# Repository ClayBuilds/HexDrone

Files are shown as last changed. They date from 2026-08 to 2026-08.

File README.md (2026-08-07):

# Folding Carbon Fiber Hexacopter

A scratch-built hexacopter with folding carbon fiber arms, positive buoyancy for
over-water recovery, and a backpack-portable transport case. Built around
salvaged 3DR and mRobotics hardware with a modern ESC and radio stack, running
ArduPilot.

**▶ [Build video and flight footage](https://youtu.be/24VfEYux5ME)**

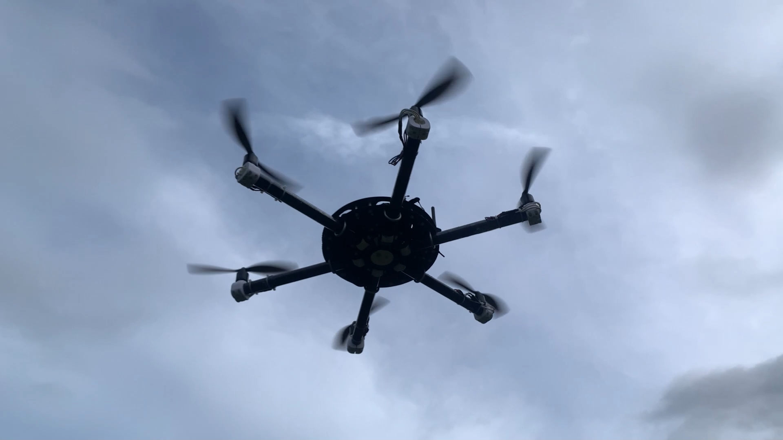
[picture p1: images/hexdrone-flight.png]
Hexacopter in flight


---

## Overview

This project started as a box of used 3DR and Pixhawk parts and grew into a
complete airframe designed around three goals:

1. **Fold for transport.** Each arm pivots on a single bolt and clamps with a
   U-bolt and thumb nuts — no tools required to deploy or stow.
2. **Float after a water landing.** Foam-filled arm tubes and printed
   lightweight-PLA floats keep the aircraft on the surface long enough to
   retrieve it.
3. **Carry it anywhere.** The folded aircraft rides in a sealed drum case with
   backpack straps.

Everything structural is either carbon fiber cut in-house or 3D printed. The
CAD, bill of materials, ArduPilot parameters, and supporting code are all in
this repository.

---

## Specifications

| | |
|---|---|
| Configuration | Hexacopter, X layout |
| Flying weight | **4.83 lb (2.19 kg)** |
| Deployed span | **36.125" prop tip to prop tip** (26.125" motor to motor) |
| Folded envelope | **9.375" diameter × 21.0" tall** |
| Total buoyancy (all floats) | 7.22 lb |
| Propellers | 6 × APC 10×4.7 SFP |
| Battery | 3S LiPo, 5600 mAh (MaxAmps 2P) |
| Thrust-to-weight | ~1.9 : 1 |
| Hover throttle | 51–54 % |
| Frame material | 1/16" carbon fiber plate, 1" OD carbon tube arms |
| Printed parts | PETG (structural), LW-PLA (floats) |
| Autopilot | mRo Control Zero Classic, ArduCopter 4.6.3 |
| Estimated build cost | **$1,382** (see [Cost](#cost) for what this includes) |

### Dimensions

| | Deployed | Folded |
|---|---|---|
| Max diameter | 36.125" (prop tip to prop tip) | **9.375"** |
| Motor centers | 26.125" | — |
| Height | 5.75" (including antennas) | 21.0" with props<br>16.0" without props |

Folding reduces maximum width by nearly 4×. In the stowed position the props
fold parallel to the arms, which accounts for the 5" difference between the
two folded heights.

---

## Measured Performance

All figures below are pulled from actual flight logs, not estimates.

### Speed and range

| Metric | Value |
|---|---|
| Max speed (manual) | **19.4 m/s — 43.3 mph** |
| Max speed (autonomous) | 10.0 m/s — limited by `WPNAV_SPEED` |
| Cruise speed, typical mission | 6.7 m/s average while moving |
| Max demonstrated distance from launch | **421 m (1381 ft)** |
| Longest logged mission | 1273 m ground track in 5.2 min |
| Max altitude flown | 114.6 m (376 ft) |

Top speed is limited by `ANGLE_MAX` (30°) and motor saturation, not by drag —
the aircraft was commanding maximum lean angle and maximum motor output
simultaneously during the fastest runs.

### Power and endurance

| Metric | Value |
|---|---|
| Hover current | ~33 A |
| Peak current observed | 63 A |
| Endurance to low-battery failsafe | ~8–9 min |
| Energy consumed, 5.2 min mission | 32.4 Wh (2863 mAh, 51 % of pack) |
| Efficiency, full mission | 39.3 m/Wh — 129 ft/Wh — 40.9 Wh/mile |
| Efficiency, cruise only (>7 m/s) | 90.3 m/Wh — 296 ft/Wh — 17.8 Wh/mile |

Cruising is roughly 2.3× more efficient per unit distance than a
waypoint-heavy mission, because hovering costs nearly the same power as
forward flight while covering no ground.

### Control performance

Attitude tracking error from a full autonomous mission after tuning:

| Axis | Mean error | 99th percentile | Max |
|---|---|---|---|
| Roll | **0.23°** | 1.43° | 2.99° |
| Pitch | **0.15°** | 1.33° | 3.04° |
| Yaw | 1.21° | 7.34° | 10.28° |

---

## Design Features

### Folding arms

Each arm is a 1" OD × 0.875" ID roll-wrapped carbon tube that pivots on a
single 1/4"-20 bolt through a printed PETG hinge. An aluminum U-bolt and two
thumb nuts clamp the tube against the frame plate to lock it deployed. A
printed arm stabilizer adds rigidity at the joint.

No tools are needed to fold or deploy the aircraft.

### Buoyancy — recovery, not survival

**This is not a waterproof aircraft.** None of the electronics are in sealed
enclosures, and a water landing will almost certainly destroy the flight
controller, ESCs, motors, and radios. The floats exist for exactly one reason:
to keep the airframe on the surface so it can be retrieved rather than lost to
the bottom.

Flying weight is 4.83 lb; total buoyancy with all floats fitted is 7.22 lb,
giving a healthy positive margin.

| Source | Buoyancy (lb) |
|---|---|
| Arms (foam-filled tubes, all 6) | 1.87 |
| Frame assembly | 0.33 |
| Central float | 0.21 |
| "Pizza slice" floats (5) | 1.00 |
| Battery displacement | 0.44 |
| Auxiliary EPS foam float | 3.37 |
| **Total** | **7.22** |

The auxiliary EPS float is fitted only for over-water flights. The printed
floats use lightweight PLA shells with foam interiors.

### Transport case

The folded aircraft rides in a 14-gallon HDPE lab-pack drum with a metal
lever-lock ring, fitted with **backpack straps**. That makes it practical to
hike a fair distance to a launch site, and the sealed drum is equally happy
being shipped or thrown in a truck bed.

Custom foam layers (waterjet-cut, sliced into smaller pieces for
manufacturability) support the body, motor arms, and prop tips. Printed prop
protectors guide the blades into their foam slots during packing.

---

## Hardware

Full details, part numbers, weights, costs, and sourcing links are in
[`Final BOM.ods`](Final%20BOM.ods) (also provided as `.xlsx`).

### Propulsion

| Item | Part | Qty |
|---|---|---|
| Motor | 3DR brushless, salvaged (12N14P) | 6 |
| ESC | Lumenier Razor Pro F4 45 A 2–6S **AM32** | 6 |
| Propeller | APC 10×4.7 SFP slow-flyer pusher | 6 |
| Battery (main) | MaxAmps 3S 5600 mAh 2P | 1 |
| Battery (alt) | Lectron Pro 3S 5200 mAh 50C | 1 |

ESCs run **DShot600**. Each has a 220 µF capacitor across the battery input.

### Avionics

| Item | Part |
|---|---|
| Flight controller | mRo Control Zero Classic (STM32F7) |
| Firmware | ArduCopter 4.6.3 |
| Power module | mRo ACSP4 — 120 A sensing, 5 V / 12 V BEC |
| GPS / compass | u-blox M8N with HMC5883 on printed mast |
| Telemetry | 915 MHz SiK-style, air + ground pair |
| RC receiver | RadioMaster RP4TD ExpressLRS 2.4 GHz diversity |
| RC transmitter | RadioMaster Pocket ELRS M2 |

### FPV

| Item | Part |
|---|---|
| VTX | SpeedyBee TX800, 25–800 mW 5.8 GHz |
| Camera | Caddx Baby Ratel 2, 1200 TVL |
| Goggles | Eachine EV800D diversity with DVR |

### Structure

| Item | Source |
|---|---|
| Frame plates (upper, middle, lower) | 1/16" DragonPlate EconomyPlate, cut in-house |
| Frame gussets (12) | Same stock |
| Arms (6) | DragonPlate 0.875" × 1.0" × 24" roll-wrapped twill tube |
| Arm pivots, motor mounts, stabilizers | 3D printed PETG |
| Floats, camera mount, GPS pedestal, antenna mount | 3D printed LW-PLA / PETG |
| Fasteners | McMaster-Carr aluminum, 4-40 / 6-32 / 1/4"-20 |

Carbon plate was cut with 1/16" DLC-coated carbide end mills.

---

## ArduPilot Configuration

Full parameter file: [`Ardupilot Parameters.params`](Ardupilot%20Parameters.params)

### Frame and motors

```
FRAME_CLASS       = 2        # Hexacopter
FRAME_TYPE        = 1        # X
MOT_PWM_TYPE      = 6        # DShot600
MOT_THST_EXPO     = 0.65
MOT_SPIN_ARM      = 0.10
MOT_SPIN_MIN      = 0.15
MOT_SPIN_MAX      = 0.95
SERVO_BLH_POLES   = 14
```

### Attitude tune

Roll and pitch gains came from a completed AutoTune run on the roll axis and
were copied to pitch (the airframe is symmetric). Yaw was set manually — see
[Known Issues](#known-issues-and-future-work).

```
ATC_RAT_RLL_P     = 0.522     ATC_RAT_PIT_P     = 0.522
ATC_RAT_RLL_I     = 0.522     ATC_RAT_PIT_I     = 0.522
ATC_RAT_RLL_D     = 0.0213    ATC_RAT_PIT_D     = 0.0213
ATC_ANG_RLL_P     = 13.062    ATC_ANG_PIT_P     = 13.062
ATC_ACCEL_R_MAX   = 82000     ATC_ACCEL_P_MAX   = 82000

ATC_RAT_YAW_P     = 0.45
ATC_RAT_YAW_I     = 0.045
ATC_RAT_YAW_D     = 0
ATC_ANG_YAW_P     = 4.5
ATC_ACCEL_Y_MAX   = 27000
```

These gains are roughly 4× the ArduPilot defaults. That is expected for a
heavy, high-inertia airframe swinging 10" props — each unit of motor output
produces a smaller, slower rotational response than on a small quad, so the
controller needs more gain to track the same command.

### Battery monitoring

Both voltage and capacity failsafes are configured. The current sensor was
calibrated empirically against measured pack consumption.

```
BATT_MONITOR      = 4         # analog voltage + current
BATT_VOLT_MULT    = 13.739
BATT_AMP_PERVLT   = 45.1      # calibrated, not the datasheet default
BATT_CAPACITY     = 5600
BATT_LOW_VOLT     = 10.4      # RTL
BATT_CRT_VOLT     = 10.0      # LAND
BATT_LOW_MAH      = 1120      # RTL at 20 % remaining
BATT_CRT_MAH      = 560       # LAND at 10 % remaining
```

### Radio link

ExpressLRS over CRSF on SERIAL5 (UART8):

```
SERIAL5_PROTOCOL  = 23        # RCIN
RC_PROTOCOLS      = 512       # CRSF only
RC_OPTIONS        = 8736      # bit 13 (ELRS 420k), bit 9 (suppress rate msg)
RSSI_TYPE         = 3         # RSSI from CRSF link
```

### Navigation and safety

```
RTL_ALT           = 2000      # 20 m — clears typical central Texas tree line
WPNAV_SPEED       = 1000      # 10 m/s
WPNAV_SPEED_UP    = 250
WPNAV_SPEED_DN    = 150
ANGLE_MAX         = 3000      # 30°
RC9_OPTION        = 4         # RTL on aux switch
ARMING_CHECK      = 13822

FENCE_TYPE        = 7         # polygon + cylinder + max altitude
FENCE_RADIUS      = 300
FENCE_ALT_MAX     = 100
FENCE_ACTION      = 1         # RTL, fallback Land
```

---

## Cost

**$1,382.26** total, but that number is a deliberate over-estimate. It counts:

- Whole sheets, tubes, and filament spools of raw stock rather than the
  fraction actually consumed
- Full fastener packs where only a few pieces are needed
- Ground equipment that never flies — transmitter, FPV goggles, ground
  telemetry radio, transport case and foam
- Tooling (carbide end mills)

Actual spend on the flying aircraft alone is substantially lower. Several
major components (motors, flight controller, GPS, power module, telemetry
radios) were sourced used from eBay.

---

## Repository Contents

```
├── README.md
├── CAD/                              # source CAD, STEP exports, STLs
├── Drone Weight Optimizer/           # battery selection tool + its own README
├── prop dyno data/
│   └── hex drone motor 3s/raw data/  # dynamometer sweeps feeding the optimizer
├── Ardupilot Parameters.params       # full parameter dump
├── Final BOM.ods                     # bill of materials (LibreOffice)
└── Final BOM excel.xlsx              # same, Excel format
```

### Drone Weight Optimizer

[`Drone Weight Optimizer/`](Drone%20Weight%20Optimizer) contains a Python tool
that picks the LiPo pack giving the longest hover time without violating
thrust or current limits. It fits a power-law curve (`I = a · T^b`) to the
propeller dynamometer data in [`prop dyno data/`](prop%20dyno%20data), predicts
hover current for each candidate battery, and ranks them while flagging any
that fail a thrust-to-weight or continuous-discharge check.

Its recommendation for this airframe was the **MaxAmps 5600 mAh 3S2P** — the
pack actually installed. Predicted hover draw was 29.6 A for 11.4 minutes;
measured flight data gives 33.1 A and roughly 10 minutes to full discharge.
The ~12 % optimism is consistent with the tool's stated simplifications, which
ignore voltage sag and assume pure hover.

See the README inside that directory for inputs, configuration, and usage.

---

## Build Notes and Lessons Learned

A few things that cost real time during this build, recorded here in case
they save someone else the trouble.

### ESC current limits

The Lumenier ESCs shipped with a current limit slider that read **"DISABLED"**
at its maximum position, but behaved as though the limit were near zero — the
motors would spin up unloaded and then refuse to accelerate past roughly 30 %
throttle with a prop installed. Moving the slider one notch off "DISABLED" to
a numerically high value (200 A) resolved it completely.

If your motors plateau under load but reach full RPM with props off, check
this before suspecting anything else.

### Compass placement is not enough on its own

An external compass on a mast still picked up severe interference once the
battery leads were repositioned near it. Field magnitude collapsed from
383 mGauss on the ground to 187 mGauss in flight — a ~350 mGauss disturbance
appearing the instant the motors drew flight current, large enough to swamp
Earth's field and corrupt the heading estimate.

The fix was routing the battery leads away from the mast and keeping the
positive and negative conductors paired. Paired leads carry equal and
opposite current, so their fields largely cancel and fall off as 1/r² instead
of 1/r.

**Verification method:** compare field magnitude with motors off versus
running. A healthy install shows almost no change. Anything more than ~10 %
warrants investigation.

### Motor mount fasteners

Two motor mounts worked loose in flight and rotated far enough to tilt the
thrust vectors. Because a tilted motor's tangential thrust component acts
through the full arm length — a much longer lever than the prop reaction
torque used for yaw control — even a few degrees of tilt produced a yaw
disturbance several times larger than the aircraft's entire yaw authority.
The result was an uncontrollable spin with all six motors saturated.

Threadlocker on motor mount fasteners is not optional on this airframe.

### AutoTune on a heavy hex

AutoTune needed several attempts and some manual intervention:

- Yaw initially failed at "Twitch Size Determination" because the stock yaw
  P gain (0.18) was far too low for this airframe. The controller never
  demanded more than 29 % of available yaw output while missing its rate
  target by 35°/s. Manually raising `ATC_RAT_YAW_P` to 0.45 fixed it.
- Ground effect matters. Tuning below ~5 m produced inconsistent results;
  10–15 m worked much better.
- Tune one axis at a time (`AUTOTUNE_AXES`). A full three-axis run does not
  fit in one battery on this aircraft.
- Enter AutoTune from LOITER, then keep hands completely off the sticks. Any
  stick input pauses progress, and AutoTune aborts after 60 seconds of
  failures.

---

## Known Issues and Future Work

- **ESC mounting is poor.** The ESCs are held to the arms with double-sided
  tape and tend to pop loose when the arms are folded and unfolded. They need
  a proper printed cradle or clamp — this is the most obvious thing on the
  list to fix.
- **Yaw tune incomplete.** The yaw axis reached the final Angle P step before
  a battery failsafe ended the session. Current yaw gains are set manually and
  track well enough (1.2° mean error), but a completed AutoTune would refine
  the angle P term.
- **No harmonic notch filtering.** Bidirectional DShot requires a `-bdshot`
  firmware variant, which is not yet flashed. Enabling it would allow
  RPM-based dynamic notch filtering and permit more aggressive gains.
- **Vibration.** Z-axis vibration peaks around 30 m/s² with no IMU clipping.
  Not currently a problem, but prop balancing is the obvious next step.

---

## Acknowledgments

Built on salvaged 3DR and mRobotics hardware. Runs
[ArduPilot](https://ardupilot.org/), whose documentation and log analysis
tooling made the tuning process tractable.

---

## License

MIT — hardware, CAD, and code alike. See [`LICENSE`](LICENSE).

Use it, modify it, build your own. Attribution appreciated but not required.

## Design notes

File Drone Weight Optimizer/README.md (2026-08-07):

# Drone Battery Flight Time Optimizer

Picks the LiPo battery that gives a multirotor the longest hover time without
violating its thrust or current limits.

The script fits a power-law curve to propeller dynamometer data (thrust vs.
current), uses that curve to predict the hover current draw for every candidate
battery, then ranks the batteries by estimated flight time and flags any that
fail a safety check.

## How it works

1. **Load inputs** — battery spec table (`.xlsx`) and a propeller dynamometer
   sweep (`.txt`).
2. **Reject outliers** — dead-band rows (zero thrust or zero current) are
   dropped, a provisional power law is fit, and points more than 2.5σ from the
   fit are removed.
3. **Fit the trendline** — `I = a · T^b`, where `T` is thrust per motor (lbs)
   and `I` is current per motor (amps). R² is reported.
4. **Estimate flight time** — for each battery:

   ```
   total_weight        = empty_weight + battery_weight
   thrust_per_motor    = total_weight / num_motors
   current_per_motor   = a · thrust_per_motor^b
   total_current       = current_per_motor · num_motors
   flight_time (min)   = (capacity_mAh / 1000) / total_current · 60
   ```

5. **Safety checks** — a battery is marked `FAIL` if either check trips:
   - **Thrust:weight** — max measured thrust × motor count must be at least
     2.0× the loaded weight.
   - **Max continuous discharge** — max measured current × motor count must not
     exceed the battery's rated continuous discharge.
6. **Report** — console summary, a text report, and a 3D scatter plot.

The recommended battery is the one with the longest flight time among those
that pass both checks.

## Requirements

Python 3 with:

```bash
pip install pandas numpy scipy matplotlib openpyxl
```

Plotting uses the `TkAgg` backend and calls `plt.show()`, so a display (and
Tk support, e.g. `python3-tk`) is needed for the interactive window. The PNG is
written either way.

## Usage

```bash
python3 drone_optimizer.py
```

Paths are relative to the working directory, so run it from the project root.

## Configuration

Edit the constants at the top of `drone_optimizer.py`:

| Constant | Default | Meaning |
| --- | --- | --- |
| `NUM_MOTORS` | `6` | Number of motors on the airframe |
| `DRONE_EMPTY_WEIGHT_LBS` | `5` | All-up weight excluding the battery |
| `THRUST_WEIGHT_RATIO` | `2.0` | Minimum required thrust:weight ratio |
| `INPUT_DATA_DIR` | `"Input Data"` | Where inputs are read from |
| `OUTPUT_DATA_DIR` | `"Output Data"` | Where results are written |

## Input files

### `Input Data/battery list.xlsx`

Sheet name must be **`MaxAmps 3S LiPo Batteries`**, with these columns:

- `Battery Name`
- `Capacity (mAh)`
- `Weight (lbs)`
- `Price ($)`
- `Max Continuous Discharge (Amps)`

### `Input Data/dynamometer_*.txt`

CSV with `#` comment lines, from a single-motor propeller dynamometer sweep.
The first matching file is used. Required columns: `THRUST_LBS`,
`CURRENT_AMPS` (`PWM_US` is present but unused).

```
# Propeller Dynamometer Test
# Recorded: 2026-03-07T20:30:48.797796
# Points:   101
# Columns:  PWM_US, THRUST_LBS, CURRENT_AMPS
#
PWM_US,THRUST_LBS,CURRENT_AMPS
1000,0.0000,0.0000
...
```

## Output files

- `Output Data/flight_time_results.txt` — parameters used, per-battery table
  with pass/fail reasons, and the recommended battery.
- `Output Data/flight_time_optimizer.png` — 3D scatter of capacity vs. battery
  weight vs. flight time. Blue circles pass, red squares fail thrust:weight,
  red triangles fail the current rating, and the green marker is the pick.

Example console/report output:

```
  Trendline Model          : I = 5.105 * T^1.541  (R² = 0.9963)
  Min Thrust:Weight Ratio  : 2.0:1  (max total thrust = 11.942 lbs)
  Max Burst Current        : 88.13 A total (14.69 A/motor x 6 motors)

OPTIMAL BATTERY:
  Name     : MAXAMPS LiPo 5600mAh 3S2P 11.1v Battery Pack
  Capacity : 5600 mAh
  Weight   : 0.869 lbs
  Flight   : 11.4 minutes
  Hover    : 29.6 A total
```

## Assumptions and limitations

- Hover only — no allowance for climb, wind, or maneuvering.
- Constant current draw for the whole discharge; voltage sag and the usable
  capacity reserve (typically ~80% depth of discharge) are not modeled.
- All motors are assumed identical to the one on the dynamometer, and thrust is
  assumed evenly split between them.
- Treat the results as a comparison between batteries, not an absolute
  endurance prediction.

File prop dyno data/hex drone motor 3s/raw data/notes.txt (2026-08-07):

Full 3s battery 2200mAh 30C lipo SPMX22003S30
Max about 2lb thrust and 15A

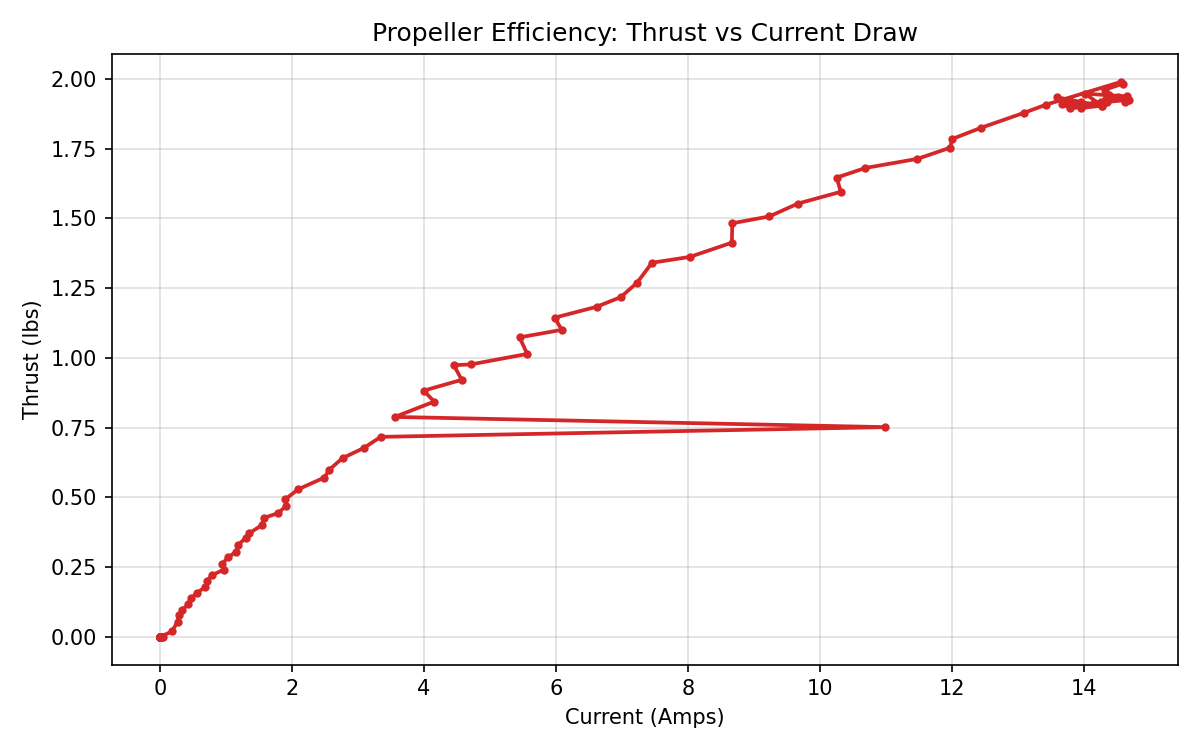
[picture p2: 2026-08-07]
Drone Weight Optimizer/Input Data/plot_thrust_vs_current_20260307_202925.png

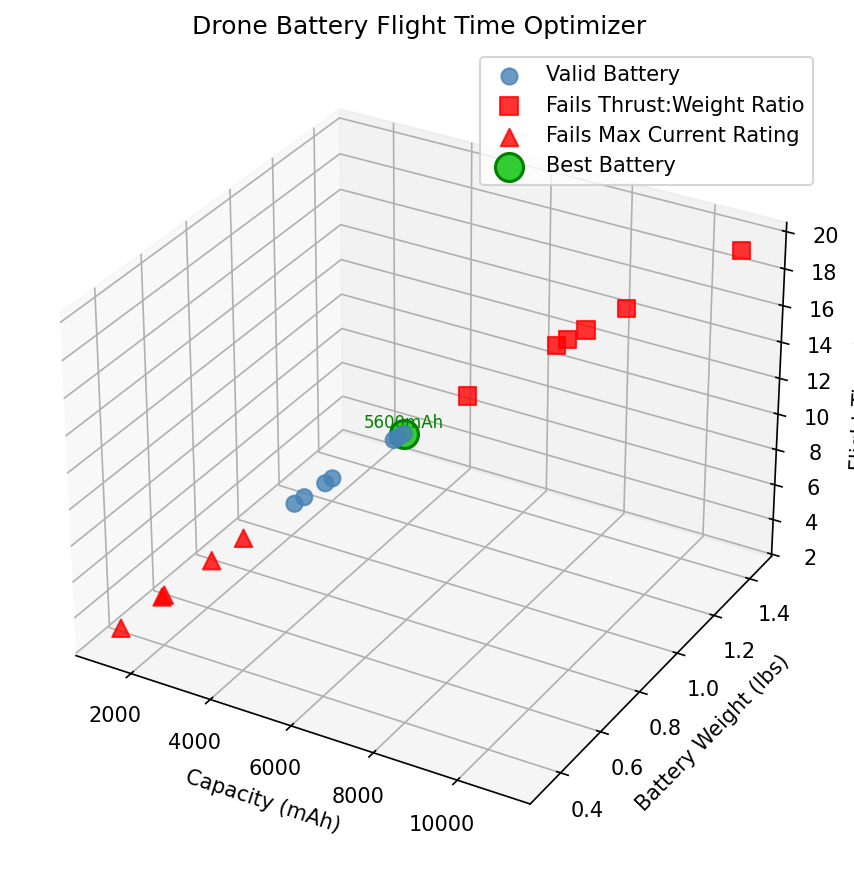
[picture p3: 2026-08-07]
Drone Weight Optimizer/Output Data/flight_time_optimizer.png

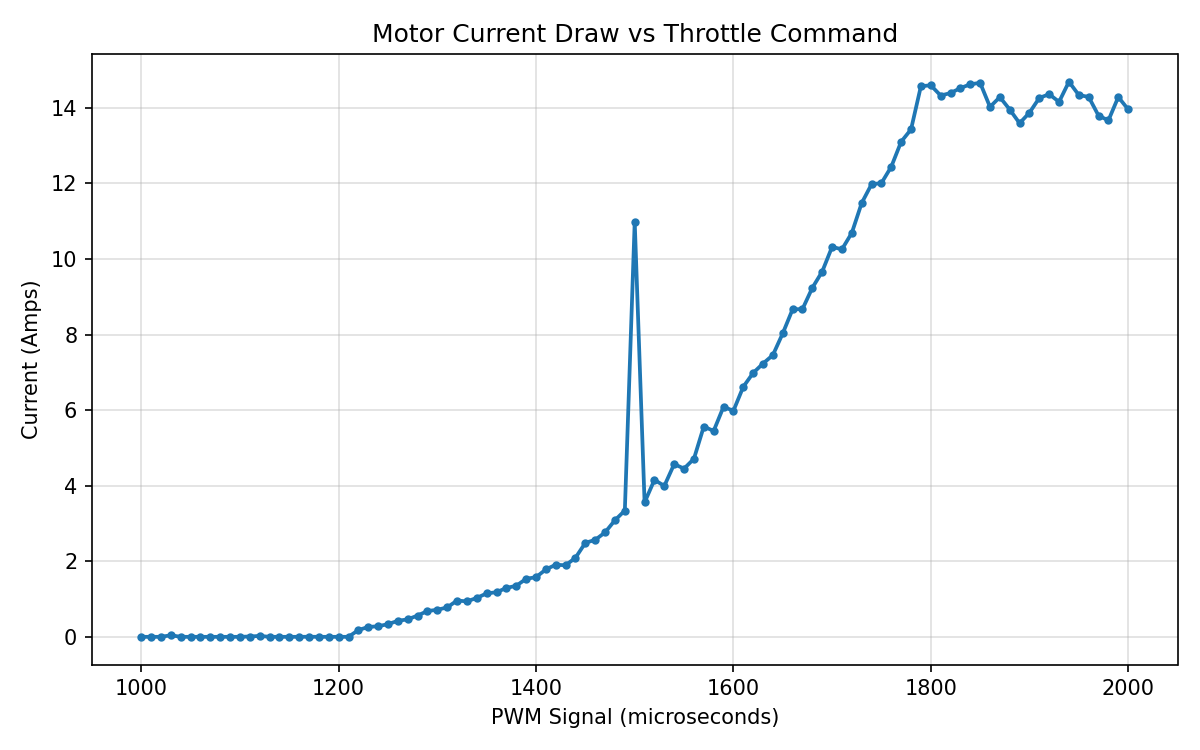
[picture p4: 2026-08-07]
prop dyno data/hex drone motor 3s/raw data/plot_current_vs_pwm_20260307_202925.png

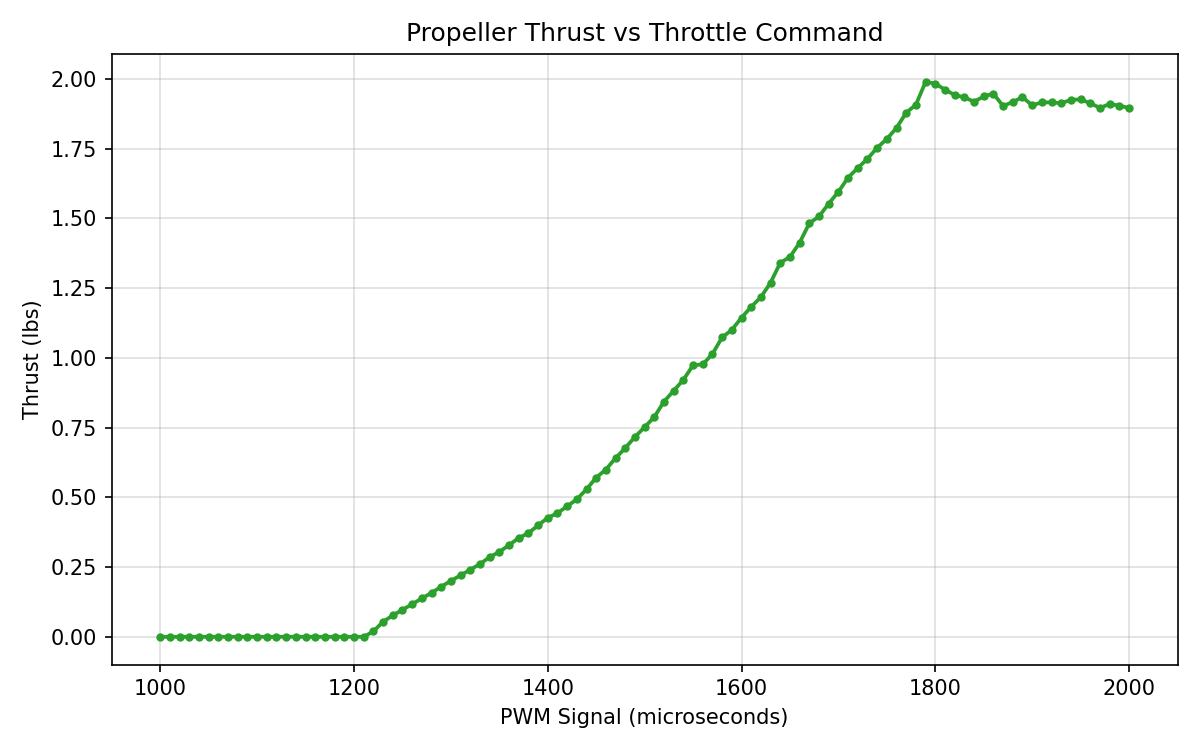
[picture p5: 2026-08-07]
prop dyno data/hex drone motor 3s/raw data/plot_thrust_vs_pwm_20260307_202925.png

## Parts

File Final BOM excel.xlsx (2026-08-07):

HEX DRONE — BILL OF MATERIALS |  |  |  |  |  |  |  |  |  |  |  |  | Corrected copy of BOM2.ods · revised 2026-08-05
Total Cost |  |  |  |  |  |  | Flying Weight (lb) |  |  |  |  |  | Buoyancy — All Floats (lb)
$1382.26 |  |  |  |  |  |  | 4.8315 |  |  |  |  |  | 7.22
Max estimate. Counts whole sheets, tubes and filament spools of raw stock rather than the fraction used, full fastener packs where only a few are needed, and ground gear that never flies — transmitter, goggles, ground radio, case and foam, end mills. Actual spend on the flying aircraft is lower.
IDENTIFICATION |  |  |  |  |  | QUANTITY & STRUCTURE |  |  | MASS & BUOYANCY |  |  |  | COST |  |  |  | SOURCING & NOTES
Item # | My P/N | Manufacturer | Manuf P/N | Name | Description | Qty per Next Assy | Total Qty | Next Assy | Count weight? | Weight Ea. (oz) | Weight Total (lb) | Buoyancy Total (lb) | Count cost? | Cost Ea. ($ per purchase) | Pack Qty (1 if not a pack) | Total Cost ($USD) | Source | Link | Notes
1 | HD0000 | - | N/A | Hex Drone Main Assembly | Full assembly — roll-up row | 1 | 1 | - | - | - | 4.8315 | 7.22 | - | - | - | $1382.26 | - |  | Totals below sum every row in the table. Rows flagged “n” in the count columns are excluded on purpose.
2 | HD0001 | 3DR | Unknown | Motor | 3-phase brushless DC, unknown origin | 1 | 6 | HD0024 | y | 2.46 | 0.9225 | - | y | $5.00 | 1 | $30.00 | eBay (used) |  | Came with 3DR drone parts. Weight includes prop nut.
~~3~~ | ~~HD0002~~ | ~~3DR~~ | ~~Unknown~~ | ~~ESC~~ | ~~3-phase BLDC ESC, 20 A, 1200–1800 µs, with 5 V BEC~~ | ~~6~~ | ~~6~~ | ~~HD0000~~ | ~~n~~ | ~~0.95~~ | ~~—~~ | ~~-~~ | ~~n~~ | ~~$5.00~~ | ~~1~~ | ~~—~~ | ~~eBay (used)~~ |  | ~~Superseded — no longer used, replaced by the Lumenier Razor Pro below. Came with 3DR drone parts. Excluded from both totals.~~
4 | HD0002 | Lumenier | 22300 | ESC | Razor Pro F4 45 A 2–6S AM32 ESC | 6 | 6 | HD0000 | y | 0.20 | 0.075 | - | y | $31.00 | 1 | $186.00 | Lumenier | lumenier.com (https://www.lumenier.com/products/lumenier-razor-pro-f4-45a-2-6s-am32-esc) | Weight includes capacitor (bare spec is 3 g).
5 | HD0003 | APC | LP10047SFP | Propeller | 10x4.7 SFP slow flyer pusher, plastic | 1 | 6 | HD0024 | y | 0.38 | 0.1425 | - | y | $1.00 | 1 | $6.00 | eBay (used) | apcprop.com/10x4-7sf-b4 (https://www.apcprop.com/product/10x4-7sf-b4/?v=7516fd43adaa) | Came with 3DR drone parts. APC spec weight is 0.42 oz; 0.38 oz measured. Link is the LP10047SF-B4 four-pack.
6 | HD0004 | mRobotics | M10048D | Flight Controller | mRo Control Zero Classic autopilot | 1 | 1 | HD0000 | y | 1.37 | 0.0856 | - | y | $80.00 | 1 | $80.00 | eBay (used) | store.3dr.com (https://store.3dr.com/control-zero-classic/) | Came with old mRo stuff. mRobotics board, sold through the 3DR store.
7 | HD0005 | mRobotics | M10026A | Power Module | mRo ACSP4 — 120 A current sensing, 42 V max, 5 V and 12 V 3 A BEC | 1 | 1 | HD0000 | y | 0.66 | 0.0413 | - | y | $19.00 | 1 | $19.00 | eBay (used) | docs.mrobotics.io/acsp4.html (https://docs.mrobotics.io/power-module/acsp4.html) | Came with old mRo stuff.
8 | HD0006 | Unknown | CKHM 2130 | Capacitor | 220 µF 63 V electrolytic capacitor | 1 | 1 | HD0000 | y | 0.08 | 0.005 | - | y | $1.00 | 1 | $1.00 | eBay (used) | - | Came with old mRo stuff.
9 | HD0007 | Unknown | Unknown | GPS Module | Generic Pixhawk GPS with compass, u-blox M8N | 1 | 1 | HD0000 | y | 1.09 | 0.0681 | - | y | $10.00 | 1 | $10.00 | eBay (used) | - | Came with old Pixhawk stuff.
10 | HD0008 | Unknown | Unknown | Telemetry Radio (Air) | 915 MHz air radio, generic Pixhawk SiK style, 6-pin, with antenna and cable | 1 | 1 | HD0000 | y | 0.55 | 0.0344 | - | y | $10.00 | 1 | $10.00 | eBay (used) | - | Came with old Pixhawk stuff. Weight includes cable.
11 | HD0009 | Unknown | Unknown | Telemetry Radio (Ground) | 915 MHz ground radio, generic Pixhawk SiK style, USB | 1 | 1 | HD0000 | n | - | — | - | y | $10.00 | 1 | $10.00 | eBay (used) | - | Came with old Pixhawk stuff. Ground station equipment — does not fly, so weight is excluded but cost is counted.
12 | HD0010 | Radiomaster | HP0157.RX-RP4TD | RC Receiver | ExpressLRS 2.4 GHz diversity receiver | 1 | 1 | HD0000 | y | 0.15 | 0.0094 | - | y | $24.99 | 1 | $24.99 | Radiomaster | radiomasterrc.com (https://radiomasterrc.com/products/rp4td-expresslrs-2-4ghz-diversity-receiver?variant=46486336372928) | Weight includes antennas (bare spec 1.4 g).
13 | HD0011 | Radiomaster | HP0157.0054-M2 | Radio Transmitter | Pocket Radio ELRS M2, FCC | 1 | 1 | HD0000 | n | - | — | - | y | $64.99 | 1 | $64.99 | Radiomaster | radiomasterrc.com (https://radiomasterrc.com/products/pocket-radio-controller-m2) | Ground station equipment — does not fly, weight excluded, cost counted.
14 | HD0012 | SpeedyBee | 16867 | VTX | SpeedyBee TX800 20×20 mm, 25–800 mW 5.8 GHz, MMCX | 1 | 1 | HD0000 | y | 0.20 | 0.0125 | - | y | $51.99 | 1 | $51.99 | RaceDayQuads | racedayquads.com (https://www.racedayquads.com/products/speedybee-tx800-20x20-25-800mw-5-8ghz-vtx-mmcx) | Spec weight 5.6 g (0.20 oz).
15 | HD0013 | Eachine | 17679 | FPV Goggles | EV800D 5.8 GHz 40CH diversity FPV goggles with DVR | 1 | 1 | HD0000 | n | - | — | - | y | $119.99 | 1 | $119.99 | RaceDayQuads | racedayquads.com (https://www.racedayquads.com/products/ev800d-5-8g-40ch-diversity-fpv-goggles-with-dvr) | Ground station equipment — does not fly, weight excluded, cost counted.
16 | HD0014 | Caddx | 15890 | FPV Camera | Baby Ratel 2, 1200 TVL CMOS, 4:3 / 16:9, NTSC/PAL, 1.8 mm, black | 1 | 1 | HD0000 | y | 0.12 | 0.0075 | - | y | $31.49 | 1 | $31.49 | RaceDayQuads | racedayquads.com (https://www.racedayquads.com/products/caddx-baby-ratel-2-1200tvl-cmos-4-3-16-9-ntsc-pal-fpv-camera-1-8mm-black) | Spec weight 3 g (0.11 oz)
17 | HD0015 | McMaster-Carr | 4083A11 | End Mill | Diamond-like carbon-coated carbide end mill, square end, 2 flute, 1/16" dia, 1-1/2" OAL | 2 | 2 | HD0000 | n | - | — | - | y | $30.83 | 1 | $61.66 | McMaster-Carr | mcmaster.com/4083A11 | Tooling for cutting out the carbon fiber sheets — does not fly, weight excluded, cost counted.
18 | HD0016 | McMaster-Carr | 3035T12 | Aluminum U-Bolt | 1/4"-20 thread size, 1" ID | 6 | 6 | HD0000 | y | 0.288 | 0.108 | - | y | $3.41 | 1 | $20.46 | McMaster-Carr | mcmaster.com/3035T12 | Weighed at 0.018 lb (0.288 oz) each. Clamps each arm tube to the frame.
19 | HD0017 | McMaster-Carr | 93886A140 | Thumb Nut | 1/4"-20 thread size, 3/4" head diameter | 12 | 12 | HD0000 | y | 0.16 | 0.120 | - | y | $11.10 | 10 | $22.20 | McMaster-Carr | mcmaster.com/93886A140 | Sold in packs of 10. 12 nuts require 2 packs.
20 | HD0018 | DragonPlate | FEPL02T*90*1212 | Carbon Fiber Sheet | EconomyPlate solid carbon fiber sheet, 1/16" × 12" × 12" | 2 | 2 | HD0000 | n | 7.184 | — | - | y | $61.65 | 1 | $123.30 | DragonPlate | dragonplate.com (https://dragonplate.com/economyplate-solid-carbon-fiber-sheet-1_16-x-12-x-12) | Raw stock — weight excluded because the finished parts (HD0020–HD0022, HD0041) are counted individually; cost is counted here once.
21 | HD0019 | DragonPlate | FDPT.875*1.0*24 | Carbon Fiber Tube | Roll-wrapped twill tube, 0.875" ID × 1.0" OD × 24", gloss finish | 3 | 3 | HD0000 | n | 4.112 | — | - | y | $59.65 | 1 | $178.95 | DragonPlate | dragonplate.com (https://dragonplate.com/carbon-fiber-roll-wrapped-twill-tube-0875-id-x-24-gloss-finish) | Raw stock — weight excluded because the arms (HD0042) are counted individually; cost is counted here once. DragonPlate lists 0.257 lb (4.11 oz) each.
22 | HD0020 | Me | - | Middle Frame Plate | Carbon fiber, cut from HD0018 | 1 | 1 | HD0023 | y | 4.48 | 0.280 | - | n | - | - | — | Made in-house | - | Cost accounted for in the raw material stock (HD0018).
23 | HD0021 | Me | - | Upper Frame Plate | Carbon fiber, cut from HD0018 | 1 | 1 | HD0023 | y | 3.52 | 0.220 | - | n | - | - | — | Made in-house | - | Cost accounted for in the raw material stock (HD0018).
24 | HD0022 | Me | - | Lower Frame Plate | Carbon fiber, cut from HD0018 | 1 | 1 | HD0023 | y | 0.16 | 0.010 | - | n | - | - | — | Made in-house | - | Cost accounted for in the raw material stock (HD0018).
25 | HD0023 | Me | - | Frame Assembly | Whole carbon frame, excluding arms | 1 | 1 | HD0000 | n | - | — | 0.33 | n | - | - | — | Made in-house | - | Subassembly — cost and weight are accounted for in its subcomponents. Buoyancy assumed from calculated volume/displacement.
26 | HD0024 | Me | - | Arm Assembly | Contains motors, tubes, mounts, etc. | 6 | 6 | HD0000 | n | - | — | - | n | - | - | — | Made in-house | - | Subassembly — cost and weight are accounted for in its subcomponents.
27 | HD0025 | Me | - | Arm Pivot | 3D printed | 1 | 6 | HD0024 | y | 0.42 | 0.1575 | - | y | $0.00 | 1 | $0.00 | 3D printed | - | Printed from PETG
28 | HD0026 | Me | - | Motor Mount | 3D printed | 1 | 6 | HD0024 | y | 0.72 | 0.270 | - | y | $0.00 | 1 | $0.00 | 3D printed | - | Printed from PETG
29 | HD0027 | McMaster-Carr | 95856A245 | 1/4-20 Lock Nut | Aluminum nylon-insert lock nut, 1/4"-20, pack of 25 | 1 | 6 | HD0024 | y | 0.064 | 0.024 | - | y | $5.28 | 25 | $5.28 | McMaster-Carr | mcmaster.com/95856A245 | Weight is per nut, not the whole pack. 6 nuts cost one pack.
30 | HD0028 | McMaster-Carr | 8127A81 | VHB Tape | Double-sided foam tape, 1/2" wide | 1 | 1 | HD0000 | n | - | — | - | y | $22.46 | 1 | $22.46 | McMaster-Carr | mcmaster.com/8127A81 | Consumable — the small amount used has negligible mass, so weight is excluded.
31 | HD0029 | McMaster-Carr | 93505A103 | Short Standoff | Male-female threaded hex standoff, aluminum, 3/16" hex, 1/2" long, 4-40 thread | 8 | 8 | HD0000 | y | 0.027 | 0.0135 | - | y | $0.50 | 1 | $4.00 | McMaster-Carr | mcmaster.com/93505A103 | -
32 | HD0030 | McMaster-Carr | 93181A007 | 6-32 Nut | Lightweight 6061 aluminum hex nut, 6-32 thread size | 18 | 18 | HD0000 | y | 0.012 | 0.0135 | - | y | $8.01 | 100 | $8.01 | McMaster-Carr | mcmaster.com/93181A007 | -
33 | HD0031 | McMaster-Carr | 93181A003 | 4-40 Nut | Lightweight 6061 aluminum hex nut, 4-40 thread size | 8 | 8 | HD0000 | y | 0.0065 | 0.0032 | - | y | $7.86 | 100 | $7.86 | McMaster-Carr | mcmaster.com/93181A003 | -
34 | HD0032 | McMaster-Carr | 98511A213 | 4-40 Screw | Aluminum socket head screw, 4-40 × 1/4" long, blue anodized | 8 | 8 | HD0000 | y | 0.007 | 0.0035 | - | y | $12.81 | 10 | $12.81 | McMaster-Carr | mcmaster.com/98511A213 | -
35 | HD0033 | McMaster-Carr | 98511A303 | 6-32 Screw | Aluminum socket head screw, 6-32 × 1/4" long, blue anodized | 18 | 18 | HD0000 | y | 0.012 | 0.0135 | - | y | $10.09 | 10 | $20.18 | McMaster-Carr | mcmaster.com/98511A303 | -
36 | HD0034 | McMaster-Carr | 93306A911 | Arm Pivot Bolt | Hex head screw, 2024 aluminum, 1/4"-20 × 1-3/4" long | 1 | 6 | HD0024 | y | 0.161 | 0.0604 | - | y | $13.99 | 10 | $13.99 | McMaster-Carr | mcmaster.com/93306A911 | -
37 | HD0035 | McMaster-Carr | 93505A446 | Long Standoff | Male-female threaded hex standoff, aluminum, 1" long, 6-32 thread | 18 | 18 | HD0000 | y | 0.16 | 0.180 | - | y | $0.54 | 1 | $9.72 | McMaster-Carr | mcmaster.com/93505A446 | -
38 | HD0036 | Me | - | FPV Camera Mount | 3D printed, fixed | 1 | 1 | HD0000 | y | 0.10 | 0.0063 | - | y | $0.00 | 1 | $0.00 | 3D printed | - | -
~~39~~ | ~~HD0037~~ | ~~Me~~ | ~~-~~ | ~~-~~ | ~~-~~ | ~~-~~ | ~~-~~ | ~~HD0000~~ | ~~n~~ | ~~-~~ | ~~—~~ | ~~-~~ | ~~-~~ | ~~-~~ | ~~-~~ | ~~—~~ | ~~-~~ | ~~-~~ | ~~Part number not used~~
40 | HD0038 | McMaster-Carr | 90362A136 | M2 Screws for Camera | Torx flat head screw, M2, stainless steel, pack of 100 | 2 | 2 | HD0000 | y | - | — | - | n | $5.70 | 100 | — | Already had | - | Weight negligible.
41 | HD0039 | Me | - | RC Antenna Mount | 3D printed; holds both the receiver and its antennas | 1 | 1 | HD0000 | y | 0.10 | 0.0063 | - | y | $0.00 | 1 | $0.00 | 3D printed | - | -
42 | HD0040 | Me | - | GPS Pedestal | 3D printed | 1 | 1 | HD0000 | y | 0.20 | 0.0125 | - | y | $0.00 | 1 | $0.00 | 3D printed | - | -
43 | HD0041 | Me | - | Frame Gusset | Carbon fiber, cut from HD0018 | 12 | 12 | HD0023 | y | 0.16 | 0.120 | - | n | - | - | — | Made in-house | - | Cost accounted for in the raw material stock (HD0018).
44 | HD0042 | Me | - | Arm | Carbon fiber tube, cut to length from stock HD0019 | 1 | 6 | HD0024 | y | 2.05 | 0.7688 | 1.87 | n | - | - | — | Made in-house | - | Cost accounted for in the raw material stock (HD0019). Buoyancy includes the internal foam and uses the full tube OD, and is the total for all 6 arms (≈ 0.31 lb each).
45 | HD0043 | ColorFabb | M-CN2-6S16 | Lightweight Filament | LW-PLA-HT, white, 1.75 mm, 750 g spool | 1 | 1 | HD0000 | n | - | — | - | y | $51.74 | 1 | $51.74 | MatterHackers | matterhackers.com/MCN26S16 (https://www.matterhackers.com/store/l/colorfabb-lw-pla-ht-075kg/sk/MCN26S16) | Raw material — weight excluded; the printed parts made from it carry their own weight. Cost is counted once here.
46 | HD0044 | Me | - | Central Float | Lightweight PLA shell with foam interior; provides emergency buoyancy | 1 | 1 | HD0000 | y | 0.50 | 0.0312 | 0.21 | y | $0.00 | 1 | $0.00 | 3D printed | - | Printed from HD0043 filament.
47 | HD0045 | APC | LPARM12SF | Prop Adapters, Metric | 8 mm to 5 mm adapter rings, 12 sets (3 / 5 / 6 mm) | 1 | 1 | HD0000 | n | - | — | - | y | $2.69 | 1 | $2.69 | APC | apcprop.com (https://www.apcprop.com/product/adapter-rings-metric-sf/?v=7516fd43adaa) | Ring mass is negligible, so weight is excluded; the set price is counted once.
48 | HD0046 | Me | - | Arm Stabilizer | 3D Printed, Provides extra rigidity to the folding arm | 1 | 6 | HD0024 | y | 0.10 | 0.0375 | - | n | - | - | — | 3D printed | - | printed, lightweight PLA
49 | HD0047 | Lectron Pro | 3S5200-50D | Alternate Battery | 3S LiPo 5200 mAh 50C, Deans connector | 1 | 1 | HD0000 | n | 11.45 | — | - | y | $69.99 | 1 | $69.99 | Hobbytown USA | - | Weight excluded — the heavier main battery (HD0056) is counted instead. This is the pack counted for cost.
50 | HD0048 | Me | - | Pizza Slice Float | Lightweight PLA shell with foam interior; provides emergency buoyancy | 5 | 5 | HD0000 | y | 0.20 | 0.0625 | 1.00 | y | $0.00 | 1 | $0.00 | 3D printed | - | Printed from HD0043 filament; the spool cost is counted once on that row. Buoyancy is the total for all 5 (0.2 lb each).
51 | HD0049 | Eagle Manufacturing | 1610MBLK | Cylindrical Container | 14 gal HDPE lab pack drum with metal lever-lock ring — main body of the case assembly | 1 | 1 | HD0050 | n | - | — | - | y | $41.51 | 1 | $41.51 | Eagle Manufacturing | eagle.justrite.com (https://eagle.justrite.com/lab-pack-open-head-poly-drum-14-gallon-metal-lever-lock-black-1610mblk) | Transport container — does not fly, so weight is excluded; cost is counted like the other ground equipment.
52 | HD0050 | Me | - | Case Assembly | Drone fits inside it for transport | 1 | 1 | HD0000 | n | - | — | - | n | - | - | — | Made in-house | - | Subassembly — does not fly, so weight is excluded; cost and weight are accounted for in its components.
53 | HD0051 | SendCutSend | - | 10" Ring Foam | Foam for the case; protects the main drone body | 3 | 3 | HD0050 | n | - | — | - | y | $5.00 | 1 | $15.00 | SendCutSend | - | Cost estimate, custom quote, sliced parts into smaller pieces for cheaper manufacturability. Some manual adjustment required
54 | HD0052 | SendCutSend | - | Lower Foam Layer | Foam for the case; supports the motor arm ends | 2 | 2 | HD0050 | n | - | — | - | y | $5.00 | 1 | $10.00 | SendCutSend | - | Cost estimate, custom quote, sliced parts into smaller pieces for cheaper manufacturability. Some manual adjustment required
55 | HD0053 | SendCutSend | - | Bottom Foam | Bottom foam piece for the case | 1 | 1 | HD0050 | n | - | — | - | y | $5.00 | 1 | $5.00 | SendCutSend | - | Cost estimate, custom quote, sliced parts into smaller pieces for cheaper manufacturability. Some manual adjustment required
56 | HD0054 | SendCutSend | - | Middle Foam | Foam for the case; goes around the motors | 3 | 3 | HD0050 | n | - | — | - | y | $5.00 | 1 | $15.00 | SendCutSend | - | Cost estimate, custom quote, sliced parts into smaller pieces for cheaper manufacturability. Some manual adjustment required
57 | HD0055 | SendCutSend | - | Top Foam | Foam for the case; holds down the top of the drone | 3 | 3 | HD0050 | n | - | — | - | y | $5.00 | 1 | $15.00 | SendCutSend | - | Cost estimate, custom quote, sliced parts into smaller pieces for cheaper manufacturability. Some manual adjustment required
58 | HD0056 | MaxAmps | Lipo-5600-3S2P-Pack-3 | Main Battery | 3S LiPo 5600 mAh (2P) | 1 | 1 | HD0000 | y | 13.69 | 0.8556 | 0.44 | n | $222.00 | 1 | — | MaxAmps | maxamps.com (https://maxamps.com/collections/3s-lipo-battery-11-1v/products/lipo-5600mah-3s2p-11-1v-battery-pack) | Weight counted — this is the heavier of the two packs. Buoyancy = pack volume (1.89 × 4.37 × 1.49 in) × 0.036 lb/in³ fresh water.
59 | HD0057 | Me | - | Auxiliary Foam Float | Attached only when flying over water; ensures positive buoyancy. Cut from EPS foam | 1 | 1 | HD0000 | y | 0.80 | 0.050 | 3.37 | n | - | - | — | Made in-house | - | Fitted only for over-water flights. Cut from EPS foam; material cost negligible.
60 | HD0058 | Me | - | Prop Protector | 3D printed; guides the prop tips into the foam case | 6 | 12 | HD0050 | n | - | — | - | y | $0.00 | 1 | $0.00 | 3D printed | - | Only used for putting the drone in the case — does not fly, weight excluded.

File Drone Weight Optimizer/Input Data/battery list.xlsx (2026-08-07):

Item # | Battery Name | Capacity (mAh) | Weight (lbs) | Price ($) | Max Continuous Discharge (Amps) | SKU | Product Link
1 | MAXAMPS LiPo 4750mAh 3S 11.1v Battery Pack | 4750 | 0.690 | $133.00 | 150 | Lipo-4750-3S-Pack-3 | https://maxamps.com/products/lipo-4750-3s-11-1v-battery-pack
2 | MAXAMPS LiPo 5450mAh 3S 11.1v Battery Pack | 5450 | 0.849 | $169.00 | 163.5 | Lipo-5450-111-Pack-F-3 | https://maxamps.com/products/lipo-5450-3s-11-1v-battery-pack
3 | MAXAMPS LiPo 5600mAh 3S2P 11.1v Battery Pack | 5600 | 0.869 | $210.00 | 140 | Lipo-5600-3S2P-Pack-3 | https://maxamps.com/products/lipo-5600mah-3s2p-11-1v-battery-pack
4 | MAXAMPS LiPo 6500mAh 3S2P 11.1v Battery Pack | 6500 | 1.001 | $210.00 | 149.5 | Lipo-6500-3S2P-Pack-3 | https://maxamps.com/products/lipo-6500-3s2p-11-1v-battery-pack
5 | MAXAMPS LiPo 8000mAh Lite 3S 11.1v Battery Pack | 8000 | 1.140 | $238.00 | 180 | Lipo-8000-Lite-3S-Pack-5 | https://maxamps.com/products/lipo-8000-3s-11-1v-battery-pack
6 | MAXAMPS LiPo 8000mAh 3S2P 11.1v Battery Pack | 8000 | 1.292 | $246.00 | 256 | Lipo-8000-3S2P-Pack-5 | https://maxamps.com/products/lipo-8000-3s2p-11-1v-battery-pack
7 | MAXAMPS LiPo 9000mAh 3S2P 11.1v Battery Pack | 9000 | 1.285 | $246.00 | 207 | Lipo-9000XL-3S2P-Pack-5 | https://maxamps.com/products/lipo-9000xl-3s-11-1v-battery-pack
8 | MAXAMPS LiPo 1300mAh 3S 11.1v Battery Pack | 1300 | 0.333 | $82.00 | 78 | Lipo-1300-3S-Pack-3 | https://maxamps.com/collections/3s-lipo-battery-11-1v/products/lipo-1300-3s-battery
9 | MAXAMPS LiPo 2000mAh 3S 11.1v Battery Pack | 2000 | 0.399 | $97.00 | 54 | Lipo-2000-3S-Pack-10 | https://maxamps.com/collections/3s-lipo-battery-11-1v/products/lipo-2000-3s-11-1v-battery-pack
10 | MAXAMPS LiPo 2800mAh 3S 11.1v Battery Pack | 2800 | 0.485 | $115.00 | 70 | Lipo-2800-3S-Pack-3 | https://maxamps.com/collections/3s-lipo-battery-11-1v/products/https-maxamps-com-collections-lipo-2800mah-packs-products-lipo-2800-3s-7-4v-battery-pack
11 | MAXAMPS LiPo 3250mAh 3S 11.1v Battery Pack | 3250 | 0.551 | $115.00 | 74.75 | Lipo-3250-3S-Pack-3 | https://maxamps.com/collections/3s-lipo-battery-11-1v/products/lipo-3250-3s-11-1v-battery-pack
12 | MAXAMPS Graphene LiPo 3750mAh 3S 11.1v Battery Pack | 3750 | 0.697 | $133.00 | 142.5 | Lipo-3750-3S-Pack-2 | https://maxamps.com/collections/3s-lipo-battery-11-1v/products/graphene-lipo-3750-3s-11-1v-battery-pack
13 | MAXAMPS LiPo 4000mAh 3S 11.1v Battery Pack | 4000 | 0.697 | $133.00 | 128 | Lipo-4000-3S-Pack-3 | https://maxamps.com/collections/3s-lipo-battery-11-1v/products/lipo-4000-3s-11-1v-battery-pack
14 | MAXAMPS LiPo 4500mAh 3S 11.1v Battery Pack | 4500 | 0.703 | $133.00 | 103.5 | Lipo-4500-3S-Pack-3 | https://maxamps.com/collections/3s-lipo-battery-11-1v/products/lipo-4500-3s-11-1v-battery-pack
15 | MAXAMPS Graphene LiPo 5200mAh 3S 11.1v Battery Pack | 5200 | 0.915 | $169.00 | 234 | Graphene-Lipo-5200-3S-Pack-2 | https://maxamps.com/collections/3s-lipo-battery-11-1v/products/graphene-lipo-5200-3s-11-1v-battery
16 | Graphene LiPo 7500mAh 3S2P 11.1v Battery Pack | 7500 | 1.305 | $246.00 | 285 | Graphene-Lipo-7500-3S2P-Pack-3 | https://maxamps.com/collections/3s-lipo-battery-11-1v/products/graphene-lipo-7500-3s2p-11-1v-battery-pack
17 | MAXAMPS LiPo 11000mAh 3S 11.1v Battery Pack | 11000 | 1.444 | $280.00 | 165 | Lipo-11000-3S-Pack-3 | https://maxamps.com/collections/3s-lipo-battery-11-1v/products/lipo-11000-3s-11-1v-battery-pack
18 | SPEKTRUM LiPo 2200mAh 3S 30C | 2200 | 0.375 |  | 66 | SPMX22003S30

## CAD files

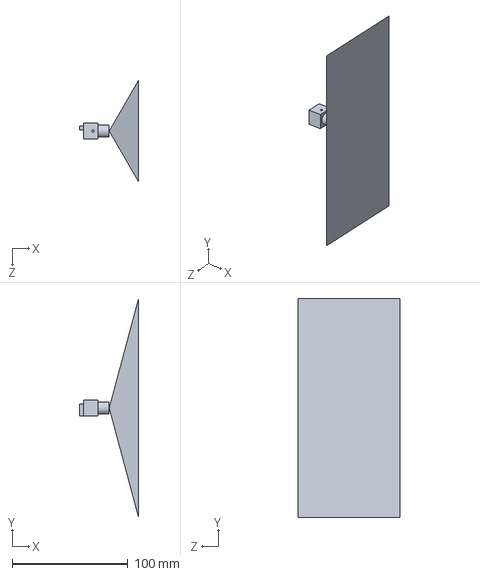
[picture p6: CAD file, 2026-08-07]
CAD/HD0014.SLDPRT
51.2 x 189.6 x 88.0 mm

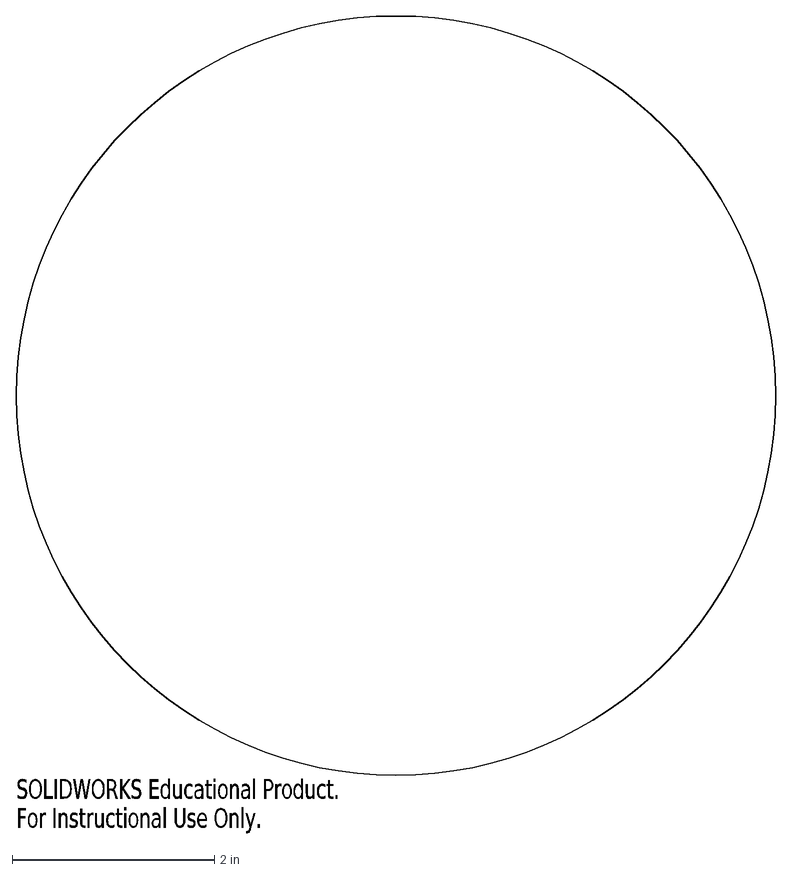
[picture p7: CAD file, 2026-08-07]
CAD/Manufacturing Files/foam cutting/HD0053.DXF
SOLIDWORKS Educational Product.
For Instructional Use Only.

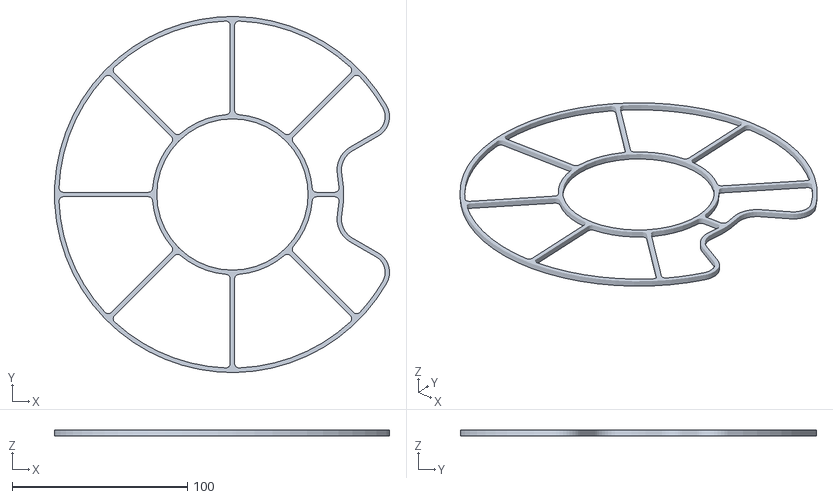
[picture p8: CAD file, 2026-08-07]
CAD/Manufacturing Files/HD0057 TRACING PATTERN.STL
191.3 x 203.2 x 3.17

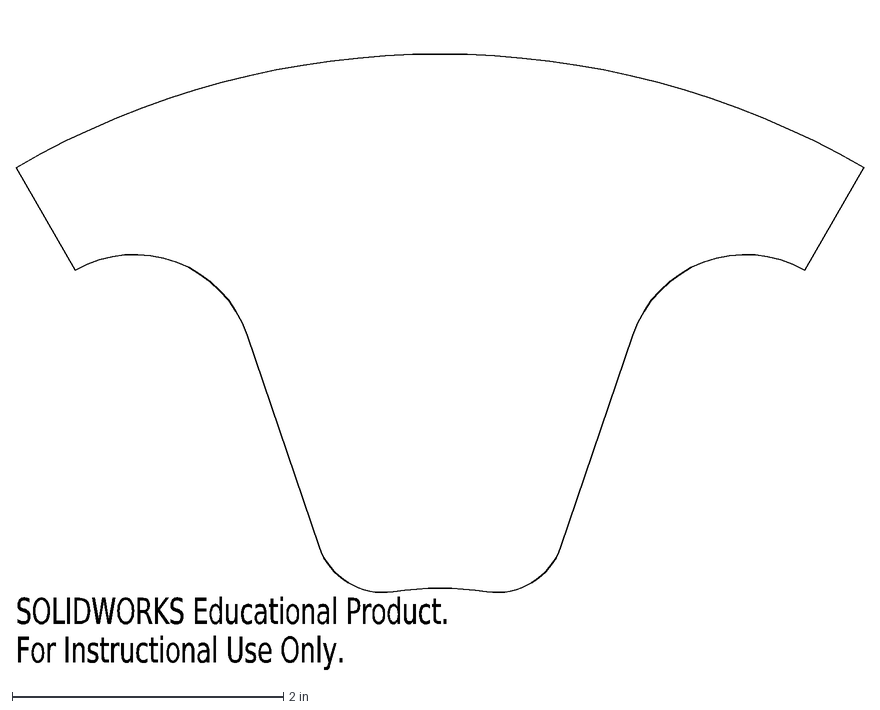
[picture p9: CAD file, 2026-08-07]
CAD/Manufacturing Files/foam cutting/HD0054-001.DXF
SOLIDWORKS Educational Product.
For Instructional Use Only.

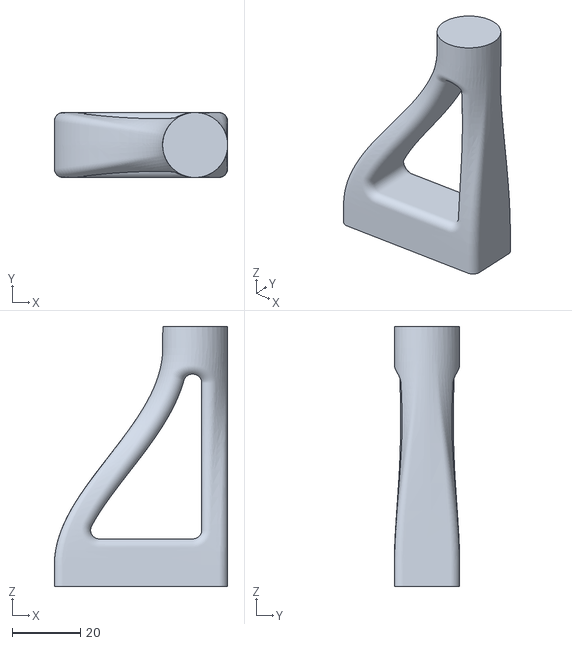
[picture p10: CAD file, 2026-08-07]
CAD/Manufacturing Files/HD0040.STL
50.8 x 19.1 x 76.2

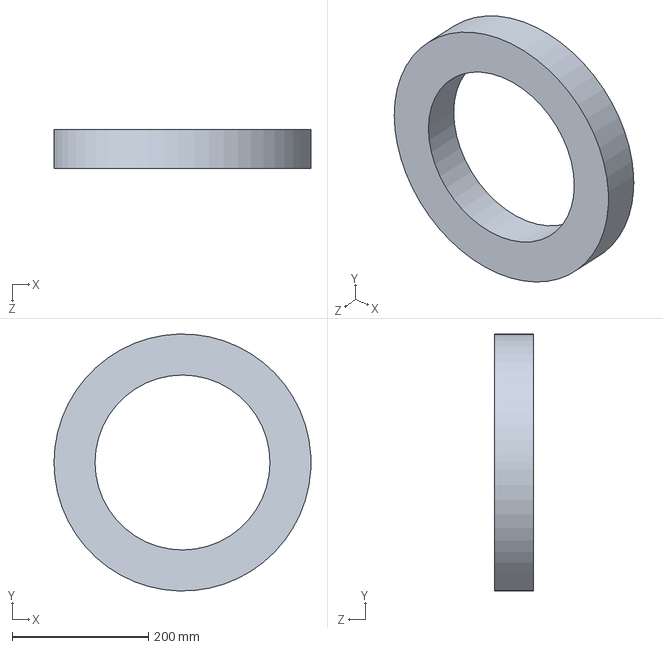
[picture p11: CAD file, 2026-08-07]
CAD/HD0051.SLDPRT
377.8 x 377.7 x 57.1 mm

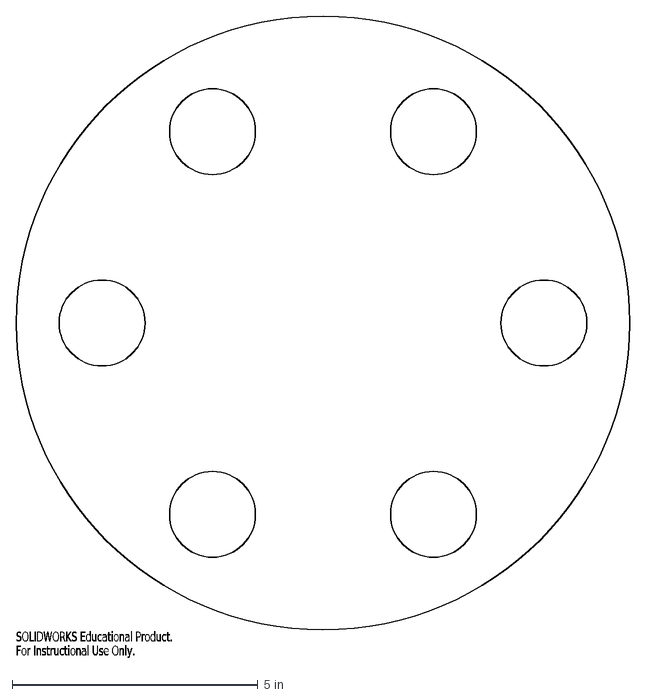
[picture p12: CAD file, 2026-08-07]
CAD/Manufacturing Files/foam cutting/HD0052.DXF
SOLIDWORKS Educational Product.
For Instructional Use Only.

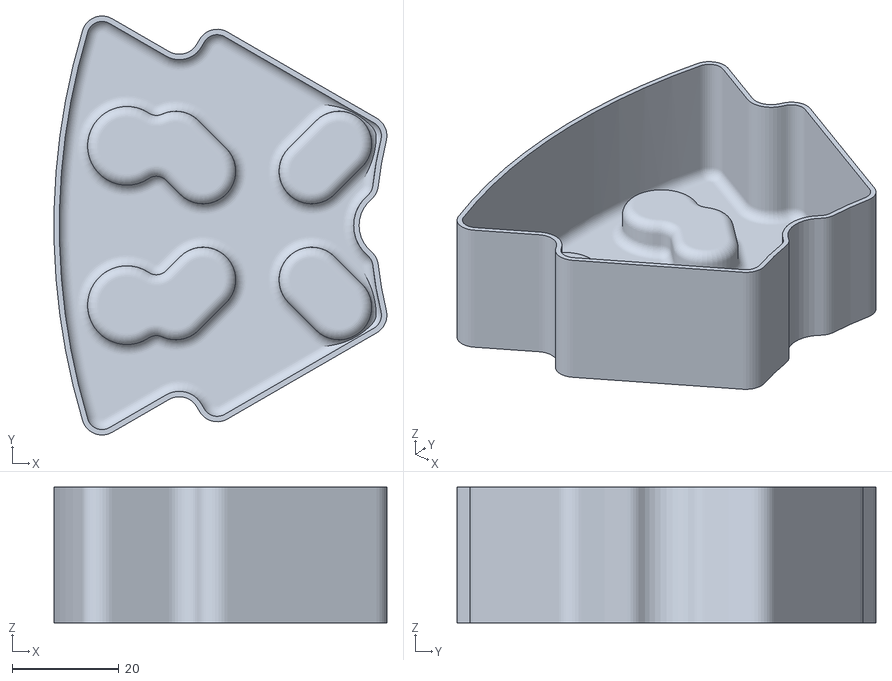
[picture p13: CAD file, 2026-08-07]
CAD/Manufacturing Files/HD0048.STL
62.3 x 78.5 x 25.4

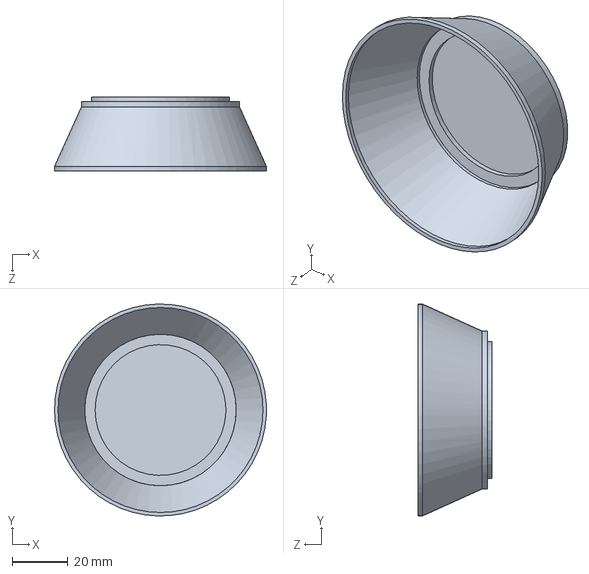
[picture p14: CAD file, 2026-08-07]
CAD/HD0044.SLDPRT
76.2 x 76.2 x 26.5 mm

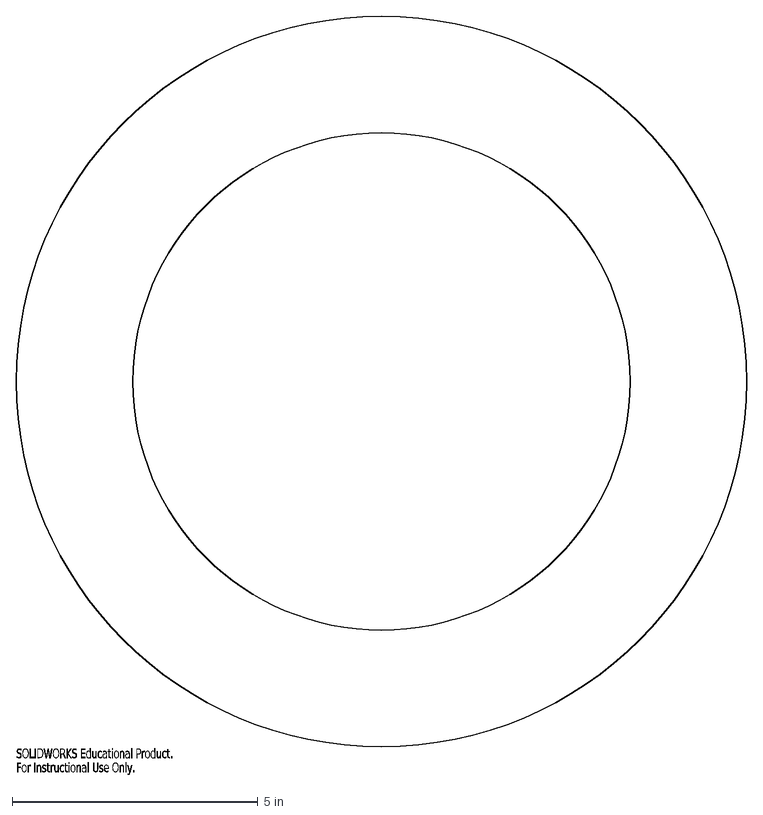
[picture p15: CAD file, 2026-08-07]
CAD/Manufacturing Files/foam cutting/HD0051.DXF
SOLIDWORKS Educational Product.
For Instructional Use Only.

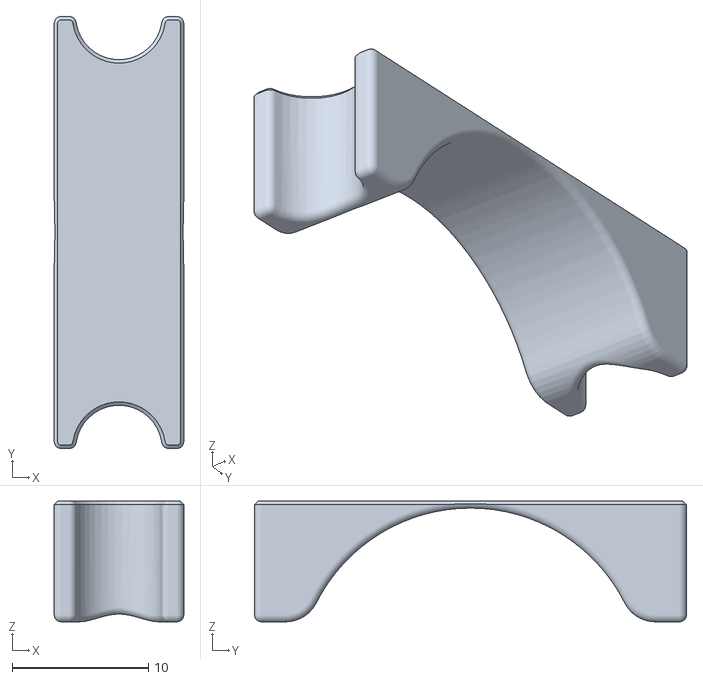
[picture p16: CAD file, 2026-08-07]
CAD/Manufacturing Files/HD0046.STL
9.52 x 31.8 x 8.86

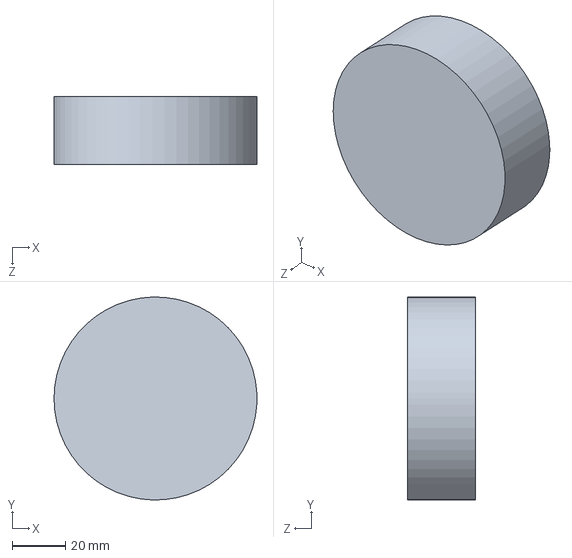
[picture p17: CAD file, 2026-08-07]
CAD/HD0055.SLDPRT
76.2 x 76.2 x 25.4 mm

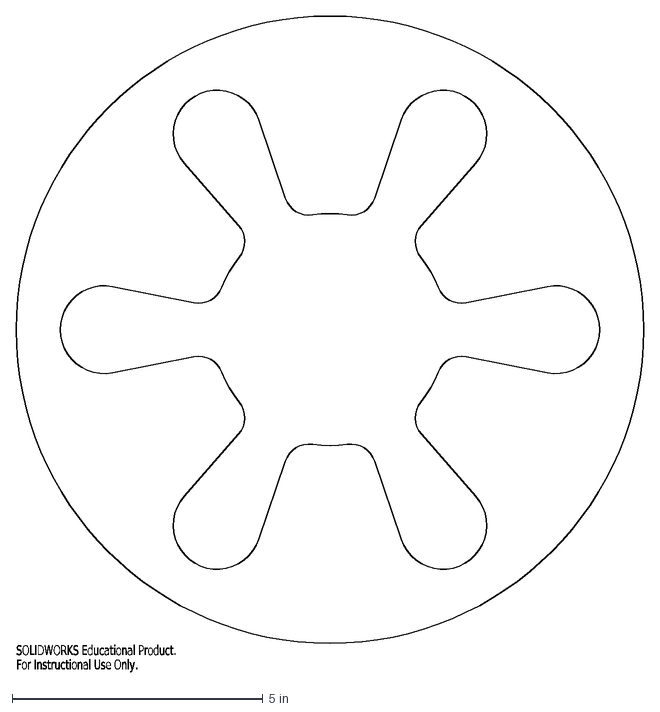
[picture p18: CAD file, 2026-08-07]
CAD/Manufacturing Files/foam cutting/HD0054.DXF
SOLIDWORKS Educational Product.
For Instructional Use Only.

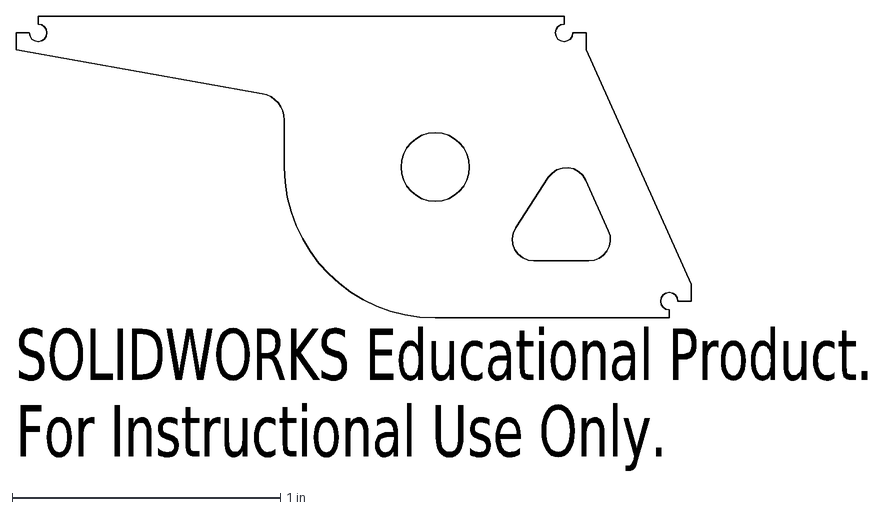
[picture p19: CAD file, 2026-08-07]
CAD/Manufacturing Files/HD0041.DXF
SOLIDWORKS Educational Product.
For Instructional Use Only.

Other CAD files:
CAD/HD0024.SLDASM
CAD/HD0050.SLDASM
CAD/HD0000.SLDASM
CAD/Manufacturing Files/foam cutting/HD0051-001.DXF
CAD/3035T12_Aluminum U-Bolt.SLDPRT
CAD/90362A136_18-8 Stainless Steel Pan Head Torx Screws.SLDPRT
CAD/93181A003_Lightweight 6061 Aluminum Hex Nuts.SLDPRT
CAD/93181A007_Lightweight 6061 Aluminum Hex Nuts.SLDPRT
CAD/93306A546_Hex Head Screw.SLDPRT
CAD/93306A911_Hex Head Screw.SLDPRT
CAD/93505A103_Male-Female Threaded Hex Standoff.SLDPRT
CAD/93505A446_Male-Female Threaded Hex Standoff.SLDPRT
CAD/93886A140_Reinforced Plastic Knurled-Head Thumb Nut.SLDPRT
CAD/95856A245_Aluminum Nylon-Insert Locknut.SLDPRT
CAD/98511A213_Aluminum Socket Head Screw.SLDPRT
CAD/98511A303_Aluminum Socket Head Screw.SLDPRT
CAD/HD0001.SLDPRT
CAD/HD0002.SLDPRT
CAD/HD0003.SLDPRT
CAD/HD0004.SLDPRT
CAD/HD0005.SLDPRT
CAD/HD0007.SLDPRT
CAD/HD0008.SLDPRT
CAD/HD0011.SLDPRT
CAD/HD0012.SLDPRT
CAD/HD0019.SLDPRT
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

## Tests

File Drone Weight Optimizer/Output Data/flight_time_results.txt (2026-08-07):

============================================================
        DRONE BATTERY FLIGHT TIME OPTIMIZER
============================================================

CALCULATION PARAMETERS:
  Number of Motors         : 6
  Empty Drone Weight       : 5.00 lbs
  Dynamometer File         : dynamometer_20260307_202925.txt
  Trendline Model          : I = 5.105 * T^1.541  (R² = 0.9963)
  Outliers Removed         : 1 point
  Min Thrust:Weight Ratio  : 2.0:1  (max single-motor thrust = 1.990 lbs, max total thrust = 11.942 lbs)
  Max Burst Current        : 88.13 A total (14.69 A/motor x 6 motors)

RESULTS:
   #  Battery Name                                         Cap      Wt   Hover A     Time  Status
  ------------------------------------------------------------------------------------------------------
   1  MAXAMPS LiPo 4750mAh 3S 11.1v Battery Pack          4750   0.690    28.22A    10.1m  OK
   2  MAXAMPS LiPo 5450mAh 3S 11.1v Battery Pack          5450   0.849    29.45A    11.1m  OK
 * 3  MAXAMPS LiPo 5600mAh 3S2P 11.1v Battery Pack        5600   0.869    29.60A    11.4m  OK
   4  MAXAMPS LiPo 6500mAh 3S2P 11.1v Battery Pack        6500   1.001    30.64A    12.7m  FAIL: Thrust:weight ratio 1.99:1 < 2.0:1 required
   5  MAXAMPS LiPo 8000mAh Lite 3S 11.1v Battery Pack     8000   1.140    31.74A    15.1m  FAIL: Thrust:weight ratio 1.94:1 < 2.0:1 required
   6  MAXAMPS LiPo 8000mAh 3S2P 11.1v Battery Pack        8000   1.292    32.96A    14.6m  FAIL: Thrust:weight ratio 1.90:1 < 2.0:1 required
   7  MAXAMPS LiPo 9000mAh 3S2P 11.1v Battery Pack        9000   1.285    32.90A    16.4m  FAIL: Thrust:weight ratio 1.90:1 < 2.0:1 required
   8  MAXAMPS LiPo 1300mAh 3S 11.1v Battery Pack          1300   0.333    25.54A     3.1m  FAIL: Max burst current 88.1A exceeds battery rating 78.0A
   9  MAXAMPS LiPo 2000mAh 3S 11.1v Battery Pack          2000   0.399    26.03A     4.6m  FAIL: Max burst current 88.1A exceeds battery rating 54.0A
  10  MAXAMPS LiPo 2800mAh 3S 11.1v Battery Pack          2800   0.485    26.67A     6.3m  FAIL: Max burst current 88.1A exceeds battery rating 70.0A
  11  MAXAMPS LiPo 3250mAh 3S 11.1v Battery Pack          3250   0.551    27.17A     7.2m  FAIL: Max burst current 88.1A exceeds battery rating 74.8A
  12  MAXAMPS Graphene LiPo 3750mAh 3S 11.1v Battery Pack    3750   0.697    28.28A     8.0m  OK
  13  MAXAMPS LiPo 4000mAh 3S 11.1v Battery Pack          4000   0.697    28.28A     8.5m  OK
  14  MAXAMPS LiPo 4500mAh 3S 11.1v Battery Pack          4500   0.703    28.32A     9.5m  OK
  15  MAXAMPS Graphene LiPo 5200mAh 3S 11.1v Battery Pack    5200   0.915    29.96A    10.4m  OK
  16  Graphene LiPo 7500mAh 3S2P 11.1v Battery Pack       7500   1.305    33.06A    13.6m  FAIL: Thrust:weight ratio 1.89:1 < 2.0:1 required
  17  MAXAMPS LiPo 11000mAh 3S 11.1v Battery Pack        11000   1.444    34.19A    19.3m  FAIL: Thrust:weight ratio 1.85:1 < 2.0:1 required
  18  SPEKTRUM LiPo 2200mAh 3S 30C                        2200   0.375    25.85A     5.1m  FAIL: Max burst current 88.1A exceeds battery rating 66.0A

OPTIMAL BATTERY:
  Name     : MAXAMPS LiPo 5600mAh 3S2P 11.1v Battery Pack
  Capacity : 5600 mAh
  Weight   : 0.869 lbs
  Price    : $210
  Flight   : 11.4 minutes
  Hover    : 29.6 A total
============================================================

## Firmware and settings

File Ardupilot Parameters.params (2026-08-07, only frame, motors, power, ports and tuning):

1	1	ATC_ANGLE_BOOST	1	2
1	1	ATC_ANG_LIM_TC	1.000000000000000000	9
1	1	ATC_ANG_PIT_P	13.062000274658203125	9
1	1	ATC_ANG_RLL_P	13.062000274658203125	9
1	1	ATC_ANG_YAW_P	4.500000000000000000	9
1	1	ATC_RATE_FF_ENAB	1	2
1	1	ATC_RATE_P_MAX	0.000000000000000000	9
1	1	ATC_RATE_R_MAX	0.000000000000000000	9
1	1	ATC_RATE_Y_MAX	0.000000000000000000	9
1	1	ATC_RAT_PIT_D	0.021299999207258224	9
1	1	ATC_RAT_PIT_D_FF	0.000000000000000000	9
1	1	ATC_RAT_PIT_FF	0.000000000000000000	9
1	1	ATC_RAT_PIT_FLTD	20.000000000000000000	9
1	1	ATC_RAT_PIT_FLTE	0.000000000000000000	9
1	1	ATC_RAT_PIT_FLTT	20.000000000000000000	9
1	1	ATC_RAT_PIT_I	0.522000014781951904	9
1	1	ATC_RAT_PIT_IMAX	0.500000000000000000	9
1	1	ATC_RAT_PIT_NEF	0	2
1	1	ATC_RAT_PIT_NTF	0	2
1	1	ATC_RAT_PIT_P	0.522000014781951904	9
1	1	ATC_RAT_PIT_PDMX	0.000000000000000000	9
1	1	ATC_RAT_PIT_SMAX	0.000000000000000000	9
1	1	ATC_RAT_RLL_D	0.021299999207258224	9
1	1	ATC_RAT_RLL_D_FF	0.000000000000000000	9
1	1	ATC_RAT_RLL_FF	0.000000000000000000	9
1	1	ATC_RAT_RLL_FLTD	20.000000000000000000	9
1	1	ATC_RAT_RLL_FLTE	0.000000000000000000	9
1	1	ATC_RAT_RLL_FLTT	20.000000000000000000	9
1	1	ATC_RAT_RLL_I	0.522000014781951904	9
1	1	ATC_RAT_RLL_IMAX	0.500000000000000000	9
1	1	ATC_RAT_RLL_NEF	0	2
1	1	ATC_RAT_RLL_NTF	0	2
1	1	ATC_RAT_RLL_P	0.522000014781951904	9
1	1	ATC_RAT_RLL_PDMX	0.000000000000000000	9
1	1	ATC_RAT_RLL_SMAX	0.000000000000000000	9
1	1	ATC_RAT_YAW_D	0.000000000000000000	9
1	1	ATC_RAT_YAW_D_FF	0.000000000000000000	9
1	1	ATC_RAT_YAW_FF	0.000000000000000000	9
1	1	ATC_RAT_YAW_FLTD	20.000000000000000000	9
1	1	ATC_RAT_YAW_FLTE	2.500000000000000000	9
1	1	ATC_RAT_YAW_FLTT	20.000000000000000000	9
1	1	ATC_RAT_YAW_I	0.045000001788139343	9
1	1	ATC_RAT_YAW_IMAX	0.500000000000000000	9
1	1	ATC_RAT_YAW_NEF	0	2
1	1	ATC_RAT_YAW_NTF	0	2
1	1	ATC_RAT_YAW_P	0.449999988079071045	9
1	1	ATC_RAT_YAW_PDMX	0.000000000000000000	9
1	1	ATC_RAT_YAW_SMAX	0.000000000000000000	9
1	1	BATT2_MONITOR	0	2
1	1	BATT3_MONITOR	0	2
1	1	BATT4_MONITOR	0	2
1	1	BATT5_MONITOR	0	2
1	1	BATT6_MONITOR	0	2
1	1	BATT7_MONITOR	0	2
1	1	BATT8_MONITOR	0	2
1	1	BATT9_MONITOR	0	2
1	1	BATT_AMP_OFFSET	0.000000000000000000	9
1	1	BATT_AMP_PERVLT	45.099998474121093750	9
1	1	BATT_ARM_MAH	0	6
1	1	BATT_ARM_VOLT	0.000000000000000000	9
1	1	BATT_CAPACITY	5600	6
1	1	BATT_CRT_MAH	560.000000000000000000	9
1	1	BATT_CRT_VOLT	10.000000000000000000	9
1	1	BATT_CURR_PIN	15	2
1	1	BATT_FS_CRT_ACT	1	2
1	1	BATT_FS_LOW_ACT	2	2
1	1	BATT_FS_VOLTSRC	0	2
1	1	BATT_LOW_MAH	1120.000000000000000000	9
1	1	BATT_LOW_TIMER	10	2
1	1	BATT_LOW_VOLT	10.399999618530273438	9
1	1	BATT_MONITOR	4	2
1	1	BATT_OPTIONS	0	6
1	1	BATT_SERIAL_NUM	-1	6
1	1	BATT_VLT_OFFSET	0.000000000000000000	9
1	1	BATT_VOLT_MULT	13.739241600036621094	9
1	1	BATT_VOLT_PIN	4	2
1	1	FLTMODE1	2	2
1	1	FLTMODE2	2	2
1	1	FLTMODE3	5	2
1	1	FLTMODE4	5	2
1	1	FLTMODE5	3	2
1	1	FLTMODE6	3	2
1	1	FLTMODE_CH	6	2
1	1	FLTMODE_GCSBLOCK	0	6
1	1	FRAME_CLASS	2	2
1	1	FRAME_TYPE	1	2
1	1	INS_GYRO_FILTER	20	4
1	1	INS_HNTCH_ENABLE	0	2
1	1	MOT_BAT_CURR_MAX	0.000000000000000000	9
1	1	MOT_BAT_CURR_TC	5.000000000000000000	9
1	1	MOT_BAT_IDX	0	2
1	1	MOT_BAT_VOLT_MAX	0.000000000000000000	9
1	1	MOT_BAT_VOLT_MIN	0.000000000000000000	9
1	1	MOT_BOOST_SCALE	0.000000000000000000	9
1	1	MOT_HOVER_LEARN	2	2
1	1	MOT_OPTIONS	0	4
1	1	MOT_PWM_MAX	2000	4
1	1	MOT_PWM_MIN	1000	4
1	1	MOT_PWM_TYPE	6	2
1	1	MOT_SAFE_DISARM	0	2
1	1	MOT_SAFE_TIME	1.000000000000000000	9
1	1	MOT_SLEW_DN_TIME	0.000000000000000000	9
1	1	MOT_SLEW_UP_TIME	0.000000000000000000	9
1	1	MOT_SPIN_ARM	0.100000001490116119	9
1	1	MOT_SPIN_MAX	0.949999988079071045	9
1	1	MOT_SPIN_MIN	0.150000005960464478	9
1	1	MOT_SPOOL_TIME	0.500000000000000000	9
1	1	MOT_SPOOL_TIM_DN	0.000000000000000000	9
1	1	MOT_THST_EXPO	0.649999976158142090	9
1	1	MOT_THST_HOVER	0.623103797435760498	9
1	1	MOT_YAW_HEADROOM	200	4
1	1	SERIAL0_BAUD	115	6
1	1	SERIAL0_PROTOCOL	2	2
1	1	SERIAL1_BAUD	57	6
1	1	SERIAL1_OPTIONS	0	4
1	1	SERIAL1_PROTOCOL	2	2
1	1	SERIAL2_BAUD	9	6
1	1	SERIAL2_OPTIONS	4	4
1	1	SERIAL2_PROTOCOL	44	2
1	1	SERIAL3_BAUD	230	6
1	1	SERIAL3_OPTIONS	0	4
1	1	SERIAL3_PROTOCOL	5	2
1	1	SERIAL4_BAUD	230	6
1	1	SERIAL4_OPTIONS	0	4
1	1	SERIAL4_PROTOCOL	5	2
1	1	SERIAL5_BAUD	115	6
1	1	SERIAL5_OPTIONS	0	4
1	1	SERIAL5_PROTOCOL	23	2
1	1	SERIAL6_BAUD	57	6
1	1	SERIAL6_OPTIONS	0	4
1	1	SERIAL6_PROTOCOL	-1	2
1	1	SERIAL7_BAUD	115	6
1	1	SERIAL7_OPTIONS	0	4
1	1	SERIAL7_PROTOCOL	2	2
1	1	SERVO1_FUNCTION	33	4
1	1	SERVO1_MAX	2000	4
1	1	SERVO1_MIN	1000	4
1	1	SERVO1_REVERSED	0	2
1	1	SERVO1_TRIM	1000	4
1	1	SERVO2_FUNCTION	34	4
1	1	SERVO2_MAX	2000	4
1	1	SERVO2_MIN	1000	4
1	1	SERVO2_REVERSED	0	2
1	1	SERVO2_TRIM	1000	4
1	1	SERVO3_FUNCTION	35	4
1	1	SERVO3_MAX	2000	4
1	1	SERVO3_MIN	1000	4
1	1	SERVO3_REVERSED	0	2
1	1	SERVO3_TRIM	1000	4
1	1	SERVO4_FUNCTION	36	4
1	1	SERVO4_MAX	2000	4
1	1	SERVO4_MIN	1000	4
1	1	SERVO4_REVERSED	0	2
1	1	SERVO4_TRIM	1000	4
1	1	SERVO5_FUNCTION	37	4
1	1	SERVO5_MAX	2000	4
1	1	SERVO5_MIN	1000	4
1	1	SERVO5_REVERSED	0	2
1	1	SERVO5_TRIM	1000	4
1	1	SERVO6_FUNCTION	38	4
1	1	SERVO6_MAX	2000	4
1	1	SERVO6_MIN	1000	4
1	1	SERVO6_REVERSED	0	2
1	1	SERVO6_TRIM	1000	4
1	1	SERVO7_FUNCTION	0	4
1	1	SERVO7_MAX	1900	4
1	1	SERVO7_MIN	1100	4
1	1	SERVO7_REVERSED	0	2
1	1	SERVO7_TRIM	1500	4
1	1	SERVO8_FUNCTION	0	4
1	1	SERVO8_MAX	1900	4
1	1	SERVO8_MIN	1100	4
1	1	SERVO8_REVERSED	0	2
1	1	SERVO8_TRIM	1500	4
1	1	SERVO9_FUNCTION	0	4
1	1	SERVO9_MAX	1900	4
1	1	SERVO9_MIN	1100	4
1	1	SERVO9_REVERSED	0	2
1	1	SERVO9_TRIM	1500	4

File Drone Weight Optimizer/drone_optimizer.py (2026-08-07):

## !/usr/bin/env python3
"""Drone Battery Flight Time Optimizer"""

import glob
import os

import matplotlib
matplotlib.use("TkAgg")
import matplotlib.pyplot as plt
import numpy as np
import pandas as pd
from scipy.optimize import curve_fit

# ── Configuration ─────────────────────────────────────────────────────────────
NUM_MOTORS = 6
DRONE_EMPTY_WEIGHT_LBS = 5
INPUT_DATA_DIR = "Input Data"
OUTPUT_DATA_DIR = "Output Data"
THRUST_WEIGHT_RATIO = 2.0   # minimum required thrust:weight ratio


# ── Data Loading ──────────────────────────────────────────────────────────────

def load_battery_data(input_dir):
    path = os.path.join(input_dir, "battery list.xlsx")
    df = pd.read_excel(path, sheet_name="MaxAmps 3S LiPo Batteries", engine="openpyxl")
    return df[["Battery Name", "Capacity (mAh)", "Weight (lbs)",
               "Price ($)", "Max Continuous Discharge (Amps)"]].copy()


def load_dynamometer_data(input_dir):
    pattern = os.path.join(input_dir, "dynamometer_*.txt")
    matches = glob.glob(pattern)
    if not matches:
        raise FileNotFoundError(f"No dynamometer file found matching: {pattern}")
    filepath = matches[0]
    filename = os.path.basename(filepath)
    df = pd.read_csv(filepath, comment="#")
    return df[["THRUST_LBS", "CURRENT_AMPS"]].copy(), filename


# ── Outlier Rejection ─────────────────────────────────────────────────────────

def _power_law(x, a, b):
    return a * np.power(x, b)


def remove_outliers(df):
    # Drop dead-band rows
    mask = (df["THRUST_LBS"] > 0) & (df["CURRENT_AMPS"] > 0)
    df_pos = df[mask].copy()

    # Fit temporary power law
    popt, _ = curve_fit(_power_law, df_pos["THRUST_LBS"], df_pos["CURRENT_AMPS"],
                        p0=[1.0, 1.5], maxfev=10000)
    predicted = _power_law(df_pos["THRUST_LBS"], *popt)
    residuals = df_pos["CURRENT_AMPS"] - predicted
    std = residuals.std()

    keep = np.abs(residuals) <= 2.5 * std
    df_clean = df_pos[keep].copy()
    n_removed = len(df_pos) - keep.sum()
    return df_clean, int(n_removed)


# ── Trendline Fitting ─────────────────────────────────────────────────────────

def fit_trendline(df_clean):
    popt, _ = curve_fit(_power_law, df_clean["THRUST_LBS"], df_clean["CURRENT_AMPS"],
                        p0=[1.0, 1.5], maxfev=10000)
    a, b = popt

    predicted = _power_law(df_clean["THRUST_LBS"], a, b)
    ss_res = np.sum((df_clean["CURRENT_AMPS"] - predicted) ** 2)
    ss_tot = np.sum((df_clean["CURRENT_AMPS"] - df_clean["CURRENT_AMPS"].mean()) ** 2)
    r2 = 1.0 - ss_res / ss_tot

    return a, b, r2


def predict_current(thrust, a, b):
    return a * thrust ** b


# ── Flight Time Calculation ───────────────────────────────────────────────────

def calculate_flight_times(batteries_df, a, b, drone_empty_weight, num_motors):
    results = batteries_df.copy()
    total_weights = drone_empty_weight + results["Weight (lbs)"]
    thrust_per_motor = total_weights / num_motors
    current_per_motor = predict_current(thrust_per_motor, a, b)
    total_current = current_per_motor * num_motors
    flight_time = (results["Capacity (mAh)"] / 1000.0) / total_current * 60.0

    results["Total_Weight_Lbs"] = total_weights
    results["Total_Current_A"] = total_current
    results["Flight_Time_Min"] = flight_time
    return results


# ── Safety Checks ─────────────────────────────────────────────────────────────

def apply_safety_checks(results_df, df_clean, num_motors, empty_weight):
    """
    Adds a 'Fail_Reasons' column (list of strings) and 'Safe' boolean column.

    Check 1 — Thrust:weight ratio
      Max thrust per motor from clean dyno data * num_motors >= 2 * total_weight

    Check 2 — Max continuous discharge
      num_motors * max clean current per motor <= battery max continuous discharge
    """
    max_thrust_per_motor = df_clean["THRUST_LBS"].max()
    max_current_per_motor = df_clean["CURRENT_AMPS"].max()
    max_total_thrust = max_thrust_per_motor * num_motors
    max_total_current = max_current_per_motor * num_motors

    fail_reasons = []
    for _, row in results_df.iterrows():
        reasons = []
        total_weight = row["Total_Weight_Lbs"]

        # Check 1: thrust:weight ratio
        ratio = max_total_thrust / total_weight
        if ratio < THRUST_WEIGHT_RATIO:
            reasons.append(
                f"Thrust:weight ratio {ratio:.2f}:1 < {THRUST_WEIGHT_RATIO:.1f}:1 required"
            )

        # Check 2: max current vs battery rating
        if max_total_current > row["Max Continuous Discharge (Amps)"]:
            reasons.append(
                f"Max burst current {max_total_current:.1f}A exceeds battery rating "
                f"{row['Max Continuous Discharge (Amps)']:.1f}A"
            )

        fail_reasons.append(reasons)

    results_df = results_df.copy()
    results_df["Fail_Reasons"] = fail_reasons
    results_df["Safe"] = results_df["Fail_Reasons"].apply(lambda r: len(r) == 0)
    results_df["Fail_TW"] = results_df["Fail_Reasons"].apply(
        lambda r: any("ratio" in s for s in r))
    results_df["Fail_Current"] = results_df["Fail_Reasons"].apply(
        lambda r: any("current" in s for s in r))
    return results_df, max_total_thrust, max_total_current


# ── 3D Scatter Plot ───────────────────────────────────────────────────────────

def plot_results(batteries_df, best_battery, output_dir):
    fig = plt.figure(figsize=(10, 7))
    ax = fig.add_subplot(111, projection="3d")

    safe = batteries_df[batteries_df["Safe"]]
    fail_tw = batteries_df[batteries_df["Fail_TW"]]
    fail_cur = batteries_df[batteries_df["Fail_Current"] & ~batteries_df["Fail_TW"]]

    # Safe batteries (blue circles)
    if not safe.empty:
        ax.scatter(safe["Capacity (mAh)"], safe["Weight (lbs)"], safe["Flight_Time_Min"],
                   c="steelblue", s=60, alpha=0.8, label="Valid Battery")

    # Thrust:weight failures (red squares)
    if not fail_tw.empty:
        ax.scatter(fail_tw["Capacity (mAh)"], fail_tw["Weight (lbs)"], fail_tw["Flight_Time_Min"],
                   c="red", s=70, marker="s", alpha=0.8, label="Fails Thrust:Weight Ratio")

    # Current failures (red triangles)
    if not fail_cur.empty:
        ax.scatter(fail_cur["Capacity (mAh)"], fail_cur["Weight (lbs)"], fail_cur["Flight_Time_Min"],
                   c="red", s=70, marker="^", alpha=0.8, label="Fails Max Current Rating")

    # Best battery (green)
    if best_battery is not None:
        bx = best_battery["Capacity (mAh)"]
        by = best_battery["Weight (lbs)"]
        bz = best_battery["Flight_Time_Min"]
        ax.scatter([bx], [by], [bz], c="limegreen", s=180, edgecolors="green",
                   linewidths=1.5, zorder=5, label="Best Battery")
        ax.text(bx, by, bz + 0.3, best_battery["Battery Name"].split()[2],
                fontsize=8, color="green", ha="center")

    ax.set_xlabel("Capacity (mAh)")
    ax.set_ylabel("Battery Weight (lbs)")
    ax.set_zlabel("Flight Time (min)")
    ax.set_title("Drone Battery Flight Time Optimizer")
    ax.legend()

    os.makedirs(output_dir, exist_ok=True)
    out_path = os.path.join(output_dir, "flight_time_optimizer.png")
    plt.savefig(out_path, dpi=150, bbox_inches="tight")
    plt.show()
    return out_path


# ── Text Results File ─────────────────────────────────────────────────────────

def save_results_txt(batteries_df, best_battery, a, b, r2, dyno_filename,
                     num_motors, empty_weight, n_outliers,
                     max_total_thrust, max_total_current, output_dir):
    os.makedirs(output_dir, exist_ok=True)
    out_path = os.path.join(output_dir, "flight_time_results.txt")

    lines = []
    sep = "=" * 60
    lines += [
        sep,
        "        DRONE BATTERY FLIGHT TIME OPTIMIZER",
        sep,
        "",
        "CALCULATION PARAMETERS:",
        f"  Number of Motors         : {num_motors}",
        f"  Empty Drone Weight       : {empty_weight:.2f} lbs",
        f"  Dynamometer File         : {dyno_filename}",
        f"  Trendline Model          : I = {a:.3f} * T^{b:.3f}  (R\u00b2 = {r2:.4f})",
        f"  Outliers Removed         : {n_outliers} point{'s' if n_outliers != 1 else ''}",
        f"  Min Thrust:Weight Ratio  : {THRUST_WEIGHT_RATIO:.1f}:1  "
        f"(max single-motor thrust = {max_total_thrust/num_motors:.3f} lbs, "
        f"max total thrust = {max_total_thrust:.3f} lbs)",
        f"  Max Burst Current        : {max_total_current:.2f} A total "
        f"({max_total_current/num_motors:.2f} A/motor x {num_motors} motors)",
        "",
        "RESULTS:",
    ]

    header = (f"  {'#':>2}  {'Battery Name':<48}  {'Cap':>6}  {'Wt':>6}  "
              f"{'Hover A':>8}  {'Time':>7}  Status")
    lines.append(header)
    lines.append("  " + "-" * (len(header) + 5))

    for i, row in batteries_df.iterrows():
        is_best = best_battery is not None and row["Battery Name"] == best_battery["Battery Name"]
        marker = " *" if is_best else "  "
        if row["Safe"]:
            status = "OK"
        else:
            status = "FAIL: " + "; ".join(row["Fail_Reasons"])
        lines.append(
            f"{marker}{i+1:>2}  {row['Battery Name']:<48}  "
            f"{int(row['Capacity (mAh)']):>6}  "
            f"{row['Weight (lbs)']:>6.3f}  "
            f"{row['Total_Current_A']:>7.2f}A  "
            f"{row['Flight_Time_Min']:>6.1f}m  "
            f"{status}"
        )

    lines += [""]
    if best_battery is not None:
        lines += [
            "OPTIMAL BATTERY:",
            f"  Name     : {best_battery['Battery Name']}",
            f"  Capacity : {int(best_battery['Capacity (mAh)'])} mAh",
            f"  Weight   : {best_battery['Weight (lbs)']:.3f} lbs",
            f"  Price    : ${best_battery['Price ($)']:.0f}",
            f"  Flight   : {best_battery['Flight_Time_Min']:.1f} minutes",
            f"  Hover    : {best_battery['Total_Current_A']:.1f} A total",
        ]
    else:
        lines.append("OPTIMAL BATTERY: None — all batteries failed safety checks.")
    lines.append(sep)

    with open(out_path, "w") as f:
        f.write("\n".join(lines) + "\n")
    return out_path


# ── Console Output ────────────────────────────────────────────────────────────

def print_summary(batteries_df, best_battery, a, b, r2, dyno_filename,
                  num_motors, empty_weight, n_outliers,
                  max_total_thrust, max_total_current):
    sep = "=" * 60
    print(sep)
    print("        DRONE BATTERY FLIGHT TIME OPTIMIZER")
    print(sep)
    print()
    print("ASSUMPTIONS:")
    print(f"  Number of Motors         : {num_motors}")
    print(f"  Empty Drone Weight       : {empty_weight:.2f} lbs")
    print(f"  Dynamometer File         : {dyno_filename}")
    print(f"  Trendline Model          : I = {a:.3f} * T^{b:.3f}  (R\u00b2 = {r2:.4f})")
    print(f"  Outliers Removed         : {n_outliers} point{'s' if n_outliers != 1 else ''}")
    print(f"  Min Thrust:Weight Ratio  : {THRUST_WEIGHT_RATIO:.1f}:1 required  "
          f"(max total thrust = {max_total_thrust:.3f} lbs)")
    print(f"  Max Burst Current        : {max_total_current:.2f} A total — "
          f"must not exceed battery's max continuous discharge rating")
    print()
    print("RESULTS:")
    header = (f"  {'#':>2}  {'Battery Name':<48}  {'Cap':>6}  {'Wt':>6}  "
              f"{'Hover A':>8}  {'Time':>7}")
    print(header)
    print("  " + "-" * (len(header) - 2))
    for i, row in batteries_df.iterrows():
        is_best = best_battery is not None and row["Battery Name"] == best_battery["Battery Name"]
        marker = " *" if is_best else "  "
        flag = "  [FAIL]" if not row["Safe"] else ""
        print(f"{marker}{i+1:>2}  {row['Battery Name']:<48}  "
              f"{int(row['Capacity (mAh)']):>6}  "
              f"{row['Weight (lbs)']:>6.3f}  "
              f"{row['Total_Current_A']:>7.2f}A  "
              f"{row['Flight_Time_Min']:>6.1f}m{flag}")
    print()
    if best_battery is not None:
        print("OPTIMAL BATTERY:")
        print(f"  Name     : {best_battery['Battery Name']}")
        print(f"  Capacity : {int(best_battery['Capacity (mAh)'])} mAh")
        print(f"  Weight   : {best_battery['Weight (lbs)']:.3f} lbs")
        print(f"  Price    : ${best_battery['Price ($)']:.0f}")
        print(f"  Flight   : {best_battery['Flight_Time_Min']:.1f} minutes")
        print(f"  Hover    : {best_battery['Total_Current_A']:.1f} A total")
    else:
        print("OPTIMAL BATTERY: None — all batteries failed safety checks.")
    print(sep)


# ── Main ──────────────────────────────────────────────────────────────────────

def main():
    batteries_df = load_battery_data(INPUT_DATA_DIR)
    dyno_df, dyno_filename = load_dynamometer_data(INPUT_DATA_DIR)

    df_clean, n_outliers = remove_outliers(dyno_df)
    a, b, r2 = fit_trendline(df_clean)

    results_df = calculate_flight_times(batteries_df, a, b,
                                        DRONE_EMPTY_WEIGHT_LBS, NUM_MOTORS)

    results_df, max_total_thrust, max_total_current = apply_safety_checks(
        results_df, df_clean, NUM_MOTORS, DRONE_EMPTY_WEIGHT_LBS
    )

    safe_df = results_df[results_df["Safe"]]
    best_battery = safe_df.loc[safe_df["Flight_Time_Min"].idxmax()] if not safe_df.empty else None

    print_summary(results_df, best_battery, a, b, r2, dyno_filename,
                  NUM_MOTORS, DRONE_EMPTY_WEIGHT_LBS, n_outliers,
                  max_total_thrust, max_total_current)

    txt_path = save_results_txt(results_df, best_battery, a, b, r2, dyno_filename,
                                NUM_MOTORS, DRONE_EMPTY_WEIGHT_LBS, n_outliers,
                                max_total_thrust, max_total_current, OUTPUT_DATA_DIR)
    print(f"\nResults saved to: {txt_path}")

    png_path = plot_results(results_df, best_battery, OUTPUT_DATA_DIR)
    print(f"Plot saved to:    {png_path}")


if __name__ == "__main__":
    main()

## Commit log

2026-08-07 Add optimization code and dyno data
    [Ardupilot Parameters.params, battery list.xlsx]
2026-08-07 cad folder
2026-08-07 add foam cutting files
    [HD0051-001.DXF, HD0051.DXF, HD0052-001.DXF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]
2026-08-07 Add all manufacturing files
    [HD0020.DXF, HD0021.DXF, HD0022.DXF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]
2026-08-07 Add main CAD files
    [3035T12_Aluminum U-Bolt.SLDPRT, 90362A136_18-8 Stainless Steel Pan Head Torx Screws.SLDPRT, 93181A003_Lightweight 6061 Aluminum Hex Nuts.SLDPRT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]
2026-08-07 add readme to the battery optimizer code
2026-08-07 update to newest ardupilot parameters
    [Ardupilot Parameters.params]
2026-08-07 add BOM
    [Final BOM excel.xlsx, Final BOM.ods]
